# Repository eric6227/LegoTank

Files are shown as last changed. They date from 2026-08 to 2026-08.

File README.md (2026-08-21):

# LEGO Tank Remote Control Project — 宏梦·初号机

一个以 ESP32 / ESP32-CAM 为硬件边缘节点、以 Python 为上位机控制层的遥控坦克与实时观测工程。项目包含完整的硬件电路设计、3D 打印结构件、LEGO 车身拼搭方案、控制固件和上位机控制软件。

效果图

> 宏梦·初号机是一台基于乐高 Technic 框架的履带遥控车，通过 WiFi + MQTT 实现远程操控与实时图传。

> [碰撞测试视频](https://www.bilibili.com/video/BV1AC866cEPq)

---

## 目录

- [1. 项目概览](#1-项目概览)
- [2. 系统架构](#2-系统架构)
- [3. 目录结构](#3-目录结构)
- [4. 硬件组成](#4-硬件组成)
- [5. MQTT 通信协议](#5-mqtt-通信协议)
- [6. 配置说明](#6-配置说明)
- [7. 伺服电机控制](#7-伺服电机控制)
- [8. 运行步骤](#8-运行步骤)
- [9. 安全说明](#9-安全说明)
- [10. 已知运行注意事项](#10-已知运行注意事项)
- [11. 许可证](#11-许可证)
- [12. 代码来源声明](#12-代码来源声明)

---

## 1. 项目概览

该仓库提供以下能力：

- 由控制软件在本地展示摄像头视频与 HUD 叠加信息。
- 通过 MQTT 接收控制板遥测包与监控板遥测包。
- 将控制板和摄像头监控板的信号强度、状态字段、统一进入 overlay 页面。
- 支持手动按键控制、蓝牙/键盘远程控制输入与视频流浏览器观测。
- 通过本地 HTTP 服务向浏览器或 OBS 端源提供稳定的 overlay 页面与 telemetry 接口。
- 提供完整的乐高拼搭说明书以及工程文件，便于复刻
- 提供完整的 3D 打印件设计（换挡器、摄像头固定座等）。
- 提供可直接在嘉立创下单的 PCB 电路板设计文件（含 Gerber、BOM、钢网）。

---

## 2. 系统架构

该工程可理解为三层：

1. **边缘硬件层**：ESP32 控制板 + ESP32-CAM 监控板固件。
2. **协议与数据层**：MQTT 主题、JSON payload 与 telemetry 语义。
3. **控制与展示层**：PyQt6 QWebEngine HUD / HTTP 页面 / Python 控制循环。

```
┌─────────────────────────────────────────────────┐
│                  上位机 (PC)                      │
│  ┌───────────────────────────────────────────┐  │
│  │  infinite_rc_controller.py                │  │
│  │  - PyQt6 HUD (QWebEngineView)             │  │
│  │  - HTTP Overlay Server (:8080)            │  │
│  │  - MQTT Client (控制指令 + 遥测)           │  │
│  │  - 键盘/手柄输入处理                       │  │
│  └───────────────────────────────────────────┘  │
└──────────────┬──────────────┬───────────────────┘
               │ MQTT         │ HTTP (视频流)
               ▼              ▼
┌──────────────────────┐  ┌──────────────────────┐
│  ESP32 控制板         │  │  ESP32-CAM 监控板     │
│  - 电机驱动 (TB6612)  │  │  - OV2640 摄像头      │
│  - 舵机控制 (M1/M2/M3)│  │  - WiFi 视频流        │
│  - 电池电压检测       │  │  - MQTT 遥测上报      │
│  - MQTT 指令接收      │  │  - 摄像头参数远程配置  │
│  - 超时安全停车       │  │                       │
└──────────────────────┘  └──────────────────────┘
```

---

## 3. 目录结构

```
legotank/
├── README.md                                 # 本文件
├── LICENSE                                   # 代码 MIT 许可证
├── MQTT_MESSAGE_FORMAT.md                    # MQTT 协议参考文档
├── requirements.txt                          # Python 运行依赖
├── config.yaml                               # 控制软件运行配置
├── .gitignore                                # Git 忽略规则
│
├── control_software/                         # 上位机控制软件
│   ├── infinite_rc_controller.py             # 主控制程序入口
│   └── config.yaml                           # 默认配置预设
│
├── legotank_esp32/                           # ESP32 控制板固件
│   ├── legotank_esp32.ino                    # 主固件源码
│   └── config.h                              # 引脚/参数配置
│
├── legotank_monitor/                         # ESP32-CAM 监控板固件
│   ├── legotank_monitor.ino                  # 主固件源码
│   ├── app_httpd.cpp                         # HTTP 视频流服务
│   ├── camera_index.h                        # 摄像头 Web 页面
│   ├── camera_pins.h                         # 摄像头引脚定义
│   ├── board_config.h                        # 板级配置
│   └── ci.yml                                # CI 构建配置
│
├── test_tools/                               # 测试与调试工具
│   ├── debug.py                              # 一键启动调试环境
│   ├── telemetry_monitor.py                  # MQTT 遥测 TUI 监控器
│   └── test_mqtt_server.py                   # MQTT 连通性测试脚本
│
├── 3D_models/                                # 3D 打印件设计
│   ├── LICENSE                               # CC0 1.0 许可证
│   ├── legotank配套打印件.FCStd              # FreeCAD 源文件
│   ├── legotank配套打印件-换挡器（2个）.stl  # 换挡器打印件
│   ├── legotank配套打印件-控制板换挡舵机固定座-1.6mmPCB.stl
│   └── legotank配套打印件-摄像头固定座.stl  # 摄像头固定座
│
├── PCBs/                                     # PCB 电路板设计
│   ├── LICENSE                               # CC0 1.0 许可证
│   ├── 说明.md                               # PCB 使用说明
│   ├── legotank.zip                          # Gerber 文件
│   ├── legotank.xlsx                         # 器件位置文件 (SMT)
│   ├── legotank-BOM.xlsx                     # BOM 器件列表
│   ├── 钢网.zip                              # 钢网文件
│   └── 乐高履带物联网遥控车.zip              # 嘉立创 EDA 工程文件
│
└── lego/                                     # LEGO 拼搭设计
    ├── LICENSE                               # CC0 1.0 许可证
    ├── legotank.io                           # Studio 设计文件
    ├── legotank.csv                          # 零件清单
    ├── legotank.xml                          # 零件 XML
    ├── legotank.pdf                          # 拼搭说明书
    └── render/
        └── legotank.png                      # 渲染效果图
```

---

## 4. 硬件组成

### 4.1 控制板 (ESP32)

| 组件 | 说明 |
|---|---|
| 主控 | ESP32 双核 240MHz |
| 电机驱动 | TB6612FNG 双路 H 桥 |
| 舵机 | M1 换挡舵机 (0-180°)、M2 大灯 (PWM)、M3 逗猫棒 (PWM) |
| 电源 | 3S LiPo (11.1V) 电池，含分压电压检测 |
| 通信 | WiFi 2.4GHz + MQTT |

### 4.2 监控板 (ESP32-CAM)

| 组件 | 说明 |
|---|---|
| 主控 | ESP32-CAM (AI-Thinker) |
| 摄像头 | OV2640 200万像素，最高 1600×1200 |
| 视频流 | MJPEG over HTTP |
| 通信 | WiFi 2.4GHz + MQTT |

### 4.3 结构件

- **防滚架**：F1 赛车级安全理念，翻滚时保护内部组件不接触地面。
- **换挡器**：两档机械变速，通过 M1 舵机切换高低档位。
> PS：其实低速档已经够快了，换挡结构比较复杂，可以使用手动挡+用绳子把挡位固定在低速（后面）
- **摄像头固定座**：安装在车体前部，提供第一视角。
- 所有结构件均为 3D 打印件，FreeCAD 源文件可供修改。

### 4.4 PCB 电路板

PCB 使用嘉立创 EDA 设计，仓库提供：
- Gerber 文件（可直接下单生产）
- BOM 器件列表（可在立创商城直接购买）
- 钢网文件（可以选择开钢网，这样焊接会方便很多，毕竟全是 0603 的贴片元件）
- 器件位置文件（用于 SMT 贴片）

---

## 5. MQTT 通信协议

本仓库中的 MQTT 通信与 JSON 字段的完整规范请见 [MQTT_MESSAGE_FORMAT.md](MQTT_MESSAGE_FORMAT.md)。

### 5.1 主题结构

| 主题 | 方向 | 说明 |
|---|---|---|
| `tank/cmd` | PC → ESP32 | 控制指令 |
| `tank/telemetry/control` | ESP32 → PC | 控制板遥测数据 |
| `tank/telemetry/monitor` | ESP32-CAM → PC | 监控板遥测数据 |
| `tank/cmd/camera` | PC → ESP32-CAM | 摄像头参数配置 |

### 5.2 控制指令字段

| 字段 | 类型 | 取值范围 | 说明 |
|---|---|---|---|
| `L` | 整数 | -255~255 | 左电机 PWM 占空比 |
| `R` | 整数 | -255~255 | 右电机 PWM 占空比 |
| `M1` | 整数 | 0~180 | 换挡舵机角度 |
| `M2` | 整数 | 0~255 | 大灯电平值 |
| `M3` | 整数 | 0~255 | 逗猫棒电平值 |

### 5.3 安全机制

- **指令超时保护 (Watchdog)**：若 500ms 内未收到任何 `tank/cmd` 消息，ESP32 自动停车。
- **电机换向保护**：（硬编码在控制板中，上位机发送指令时也会遵守）检测到方向切换时先强制输出 0 一段时间，保护驱动电路。

---

## 6. 配置说明

### 6.1 控制软件配置

控制软件使用 [control_software/config.yaml](control_software/config.yaml) 作为默认预设配置文件。配置文件不存在时会自动生成默认配置文件。

该文件包含：

- **MQTT 连接**：broker 地址、端口、订阅主题。
- **视频流**：stream_url、分辨率、画质、帧率。
- **控制参数**：按键绑定、功率上限、加速率、制动强度、转向因子。
- **换挡参数**：高低档位阈值、换挡时间、M1 舵机角度。
- **伺服电机**：数量、名称、段数、idle 电平、各段按键/电平/过渡时间/触发方式。
- **视频处理**：翻转、旋转、自动画质调节。

控制软件在启动时会优先从同目录下的 YAML 文件读取参数，并在代码里用 `DEFAULT_CONFIG` 作为代码级默认兜底。

### 6.2 控制板固件配置

控制板配置见 [legotank_esp32/config.h](legotank_esp32/config.h)，包含：

- 引脚定义（电机、舵机、电池检测）
- PWM 参数（频率、分辨率）
- 电池分压电阻值
- WiFi / MQTT 连接参数
- 运行时参数（遥测间隔、看门狗超时、换向保护时间）

---

## 7. 伺服电机控制

控制软件通过"伺服电机"设置页提供灵活的伺服电机分段控制：

- **数量**：可配置 1~8 个伺服电机（默认 2 个），M1 留给换挡舵机专用。
- **段数**：每个伺服电机可独立配置 1~8 段，动态增减段数后界面自动重建。
- **电平值**：使用 0~255 电平值而非角度，M2/M3 引脚直接输出 PWM（频率 1200Hz，分辨率 8bit），消除 LED 频闪。
- **不触发电平**：每个伺服电机有独立的 idle 电平值。
- **触发方式**：每段支持"按住触发"（按下生效，释放回 idle）和"按键切换"（按一次切换，再按一次回 idle）两种模式。
- **平滑过渡**：每段可配置独立的过渡时间，伺服电机会在设定时间内平滑过渡到目标电平。

按键行为逻辑：
- **按键切换**：当前为该段 → 回到不触发；当前不是该段 → 切换到该段。
- **按住触发**：按住 → 切到该段；释放 → 回到不触发。
- 在任意一段按下另一段的按键，就切换到那一段。

---

## 8. 运行步骤

### 8.1 环境准备

1. 安装 Python 依赖：

   ```bash
   pip install -r requirements.txt
   ```

2. 确保 MQTT Broker（如 Mosquitto）在局域网内正常运行。

3. 将 ESP32 控制板和 ESP32-CAM 监控板固件分别烧录到对应硬件。

### 8.2 启动控制软件

```bash
python control_software/infinite_rc_controller.py
```

### 8.3 测试工具

- **遥测监控**：`python test_tools/telemetry_monitor.py` — TUI 界面实时查看控制板和监控板遥测数据。
- **连通性测试**：`python test_tools/test_mqtt_server.py` — 验证 MQTT Broker 是否正常工作。
- **一键调试**：`python test_tools/debug.py` — 同时启动控制软件和遥测监控。

### 8.4 快速 MQTT 测试

```bash
# 发送控制指令
mosquitto_pub -h 192.168.2.45 -t tank/cmd -m '{"L":200,"R":200}'

# 订阅遥测
mosquitto_sub -h 192.168.2.45 -t tank/telemetry/control
```

---

## 9. 安全说明

该项目当前的通信设计是：

- MQTT Broker 连接：默认基于 TCP / 1883 端口。
- MQTT 载荷：JSON 文本，未做协议层加密。
- 视频流：HTTP / 视频源地址，由本地网络环境提供。

因此，当前工程存在明显的安全限制：

- 消息在网络中没有 TLS / SSL / MQTT over TLS 的保护。
- 车体命令、遥测、RSSI、系统状态等都可能以明文形式经过网络。
- 设备接入环境应当控制在受信任的局域网，或后续增加 VPN / SSH 隧道 / MQTT TLS / 设备级认证后再投入真实生产场景。

---

## 10. 已知运行注意事项

- 该项目是物理硬件驱动型工程，强依赖网络与 MQTT Broker 可达性。
- 如果设备没有实时发布消息，控制软件会在界面中持续显示等待状态。
- `telemetry_monitor.py` 是排查 MQTT 输出字段与主题路由的辅助工具。
- 如果某个字段没有被摄像头监控板或控制板正常填充，窗口 HUD 也会出现"图层灰"/"缺字段"的显示现象。
- ESP32-CAM 监控板需设置静态 IP，确保视频流地址稳定。

---

## 11. 许可证

本项目采用**双许可证**模式，按文件类型分别适用不同协议：

| 内容类型 | 许可协议 | 适用范围 |
|---|---|---|
| **代码** | [MIT License](./LICENSE) | `.py`、`.ino`、`.cpp`、`.h`、`.yml`、`.yaml` 等源代码文件 |
| **3D 模型** | [CC0 1.0](./3D_models/LICENSE) | `.stl`、`.FCStd` 等 3D 打印设计文件 |
| **PCB 设计** | [CC0 1.0](./PCBs/LICENSE) | Gerber、BOM、钢网、位置文件等电路板设计文件 |
| **LEGO 设计** | [CC0 1.0](./lego/LICENSE) | `.io`、`.xml`、`.csv`、`.pdf` 等乐高拼搭设计文件 |
| **文档** | [CC0 1.0](./README.md) | `README.md`、`MQTT_MESSAGE_FORMAT.md`、`视频文案.md` 等文档 |

简单来说：
- **代码**：MIT 协议，可自由使用、修改、分发，需保留版权声明。
- **非代码资产**（3D 模型、PCB、LEGO 设计、文档）：CC0 1.0 协议，完全贡献至公共领域，可自由使用、修改、分发（含商业用途），无需署名。

各目录下的 `LICENSE` 文件为该目录内容的许可协议，具有法律效力。

---

## 12. 代码来源声明

本仓库中的可执行代码、协议处理与工程骨架由 AI 辅助工具生成或改写。代码不仅可用于功能验证，也可以作为后续硬件控制系统的演进基础。使用者应当自行验证所有字段、协议、设备连接与安全策略是否适用于实际应用场景。使用者不规范使用或者失误造成的后果与开发者本人无关。

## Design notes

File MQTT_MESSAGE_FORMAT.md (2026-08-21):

# 玩具坦克 ESP32 MQTT 通信协议

> 适用固件：`legotank_esp32/legotank_esp32.ino`

## 1. 控制指令（上位机 → ESP32）

**Topic：** `tank/cmd`

**格式：** JSON，UTF-8 文本

### 字段说明

| 字段 | 类型 | 取值范围 | 说明 |
| ---- | --- | --- | --- |
| `L`  | 整数 | `-255 ~ 255`  | 左电机 PWM 占空比，负值倒车，正值前进  |
| `R`  | 整数 | `-255 ~ 255`  | 右电机 PWM 占空比，负值倒车，正值前进  |
| `M1` | 整数 | `0 ~ 180` | 换挡舵机角度（0° ~ 180°） |
| `M2` | 整数 | `0 ~ 255` | 大灯电平值（直接 PWM 占空比，0=关闭，255=最亮）  |
| `M3` | 整数 | `0 ~ 255` | 逗猫棒电平值（直接 PWM 占空比，0=关闭，255=最大）  |

- 所有字段均为**可选**；缺失的字段保持上一次值不变。
- 动力差转向、差速调速等逻辑必须在上位机完成，ESP32 直接使用原始值驱动硬件。
- M2/M3 使用直接 PWM 控制（频率 1200Hz，分辨率 8bit），可有效消除 LED 频闪。

### 示例

```json
{
  "L": 200,
  "R": -150,
  "M1": 90,
  "M2": 128,
  "M3": 0
}
```

含义：

- 左电机以 `200/255` 功率前进
- 右电机以 `150/255` 功率倒车
- M1 舵机回到中位
- M2 大灯电平 128（半亮）
- M3 逗猫棒电平 0（关闭）

### 仅控制舵机示例

```json
{
  "M1": 120,
  "M3": 255
}
```

电机保持当前状态不变。

---

## 2. 遥测数据（ESP32 → 上位机）

**Topic：** `tank/telemetry`

**格式：** JSON，发送间隔约 `500ms`（可在 `config.h` 中修改 `TELEMETRY_MS`）

### 字段说明

| 字段 | 类型 | 单位 | 说明 |
| --- | --- | --- | --- |
| `vbat`  | 浮点数 | V | 3S LiPo 电池电压 |
| `L` | 整数 | `-255~255` | 当前左电机实际输出 |
| `R` | 整数 | `-255~255` | 当前右电机实际输出 |
| `M1` | 整数 | `0~180`  | 当前 M1 舵机角度 |
| `M2` | 整数 | `0~255`  | 当前 M2 电平（大灯） |
| `M3` | 整数 | `0~255`  | 当前 M3 电平（逗猫棒） |
| `rssi`  | 整数 | dBm | WiFi 信号强度 |
| `uptime`| 整数 | ms | ESP32 运行时间 |

### 示例

```json
{
  "vbat": 11.34,
  "L": 200,
  "R": -150,
  "M1": 90,
  "M2": 128,
  "M3": 0,
  "rssi": -45,
  "uptime": 123456
}
```

---

## 3. 安全机制

- **指令超时保护（Watchdog）：** 若 `1000ms` 内未收到任何 `tank/cmd` 消息，ESP32 会自动将左右电机置 0（停车），舵机保持原位。
- 该机制可防止上位机崩溃、网络中断或程序异常时坦克失控。

---

## 4. 快速测试

使用 `mosquitto_pub` 或任意 MQTT 客户端向 `tank/cmd` 发送：

```bash
mosquitto_pub -h 192.168.2.45 -t tank/cmd -m '{"L":200,"R":200}'
```

订阅遥测：

```bash
mosquitto_sub -h 192.168.2.45 -t tank/telemetry
```

> 请将 `192.168.2.45` 替换为实际 MQTT 服务器地址（在 `config.h` 中配置）。

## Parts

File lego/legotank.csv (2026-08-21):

BLItemNo | ElementId | LdrawId | PartName | BLColorId | LDrawColorId | ColorName | ColorCategory | Qty | Weight
14720 | 6396959 | 14720.dat | Technic, Liftarm, Modified H-Shape Thick 3 x 5 Perpendicular | 85 | 72 | Dark Bluish Gray | Solid Colors | 2
15100 | 6282142 | 15100.dat | Technic, Pin with Friction Ridges and Pin Hole | 86 | 71 | Light Bluish Gray | Solid Colors | 2 | 0.4
15100 | 6282140 | 15100.dat | Technic, Pin with Friction Ridges and Pin Hole | 11 | 0 | Black | Solid Colors | 4 | 0.4
15458 | 6127205 | 15458.dat | Technic, Panel Plate 3 x 11 x 1 | 85 | 72 | Dark Bluish Gray | Solid Colors | 3 | 7
18654 | 6183784 | 18654.dat | Technic, Liftarm Thick 1 x 1 (Spacer) | 86 | 71 | Light Bluish Gray | Solid Colors | 4 | 0.17
18946 | 6100930 | 18946.dat | Technic, Gear 16 Tooth with Clutch on Both Sides | 5 | 4 | Red | Solid Colors | 4 | 0.84
18947 | 6100931 | 18947.dat | Technic Driving Ring 3L | 85 | 72 | Dark Bluish Gray | Solid Colors | 2 | 1.97
22961 | 6123815 | 22961.dat | Technic, Axle and Pin Connector Hub with 1L Axle | 86 | 71 | Light Bluish Gray | Solid Colors | 2 | 0.34
26287 | 6273211 | 26287.dat | Technic, Axle Connector 3L | 5 | 4 | Red | Solid Colors | 2 | 0.7
2780 | 6279875 | 2780.dat | Technic, Pin with Short Friction Ridges | 11 | 0 | Black | Solid Colors | 83 | 0.16
32054 | 6347789 | 32054.dat | Technic, Pin 3L with Friction Ridges and Stop Bush | 5 | 4 | Red | Solid Colors | 8 | 0.33
32062 | 4142865 | 32062.dat | Technic, Axle 2L Notched | 5 | 4 | Red | Solid Colors | 2 | 0.26
32073 | 4211639 | 32073.dat | Technic, Axle 5L | 86 | 71 | Light Bluish Gray | Solid Colors | 4 | 0.66
4265c | 6271167 | 32123a.dat | Technic Bush 1/2 Smooth | 3 | 14 | Yellow | Solid Colors | 2 | 0.1
32198 | 6031956 | 32198.dat | Technic, Gear 20 Tooth Bevel | 86 | 71 | Light Bluish Gray | Solid Colors | 2 | 0.75
32269 | 6346535 | 32269.dat | Technic, Gear 20 Tooth Double Bevel | 11 | 0 | Black | Solid Colors | 4 | 1.4
32278 | 4542576 | 32278.dat | Technic, Liftarm Thick 1 x 15 | 85 | 72 | Dark Bluish Gray | Solid Colors | 4 | 4
32278 | 4542577 | 32278.dat | Technic, Liftarm Thick 1 x 15 | 86 | 71 | Light Bluish Gray | Solid Colors | 1 | 4
32291 | 6280394 | 32291.dat | Technic, Axle and Pin Connector Perpendicular Double | 11 | 0 | Black | Solid Colors | 1 | 0.6
32316 | 4142132 | 32316.dat | Technic, Liftarm Thick 1 x 5 | 5 | 4 | Red | Solid Colors | 2 | 1.21
32316 | 4211651 | 32316.dat | Technic, Liftarm Thick 1 x 5 | 86 | 71 | Light Bluish Gray | Solid Colors | 3 | 1.21
32524 | 4495931 | 32524.dat | Technic, Liftarm Thick 1 x 7 | 85 | 72 | Dark Bluish Gray | Solid Colors | 9 | 1.74
32524 | 4495933 | 32524.dat | Technic, Liftarm Thick 1 x 7 | 5 | 4 | Red | Solid Colors | 2 | 1.74
32524 | 4495930 | 32524.dat | Technic, Liftarm Thick 1 x 7 | 86 | 71 | Light Bluish Gray | Solid Colors | 2 | 1.74
32526 | 4211713 | 32526.dat | Technic, Liftarm, Modified Bent Thick L-Shape 3 x 5 | 86 | 71 | Light Bluish Gray | Solid Colors | 4 | 1.77
3705 | 370526 | 3705.dat | Technic, Axle 4L | 11 | 0 | Black | Solid Colors | 6 | 0.6
3707 | 370726 | 3707.dat | Technic, Axle 8L | 11 | 0 | Black | Solid Colors | 2 | 1.18
3713 | 6275844 | 3713.dat | Technic Bush | 86 | 71 | Light Bluish Gray | Solid Colors | 14 | 0.14
3737 | 373726 | 3737.dat | Technic, Axle 10L | 11 | 0 | Black | Solid Colors | 2 | 1.49
40490 | 6102449 | 40490.dat | Technic, Liftarm Thick 1 x 9 | 86 | 71 | Light Bluish Gray | Solid Colors | 1 | 2.59
44294 | 4211805 | 44294.dat | Technic, Axle 7L | 86 | 71 | Light Bluish Gray | Solid Colors | 1 | 1.05
4519 | 4211815 | 4519.dat | Technic, Axle 3L | 86 | 71 | Light Bluish Gray | Solid Colors | 2 | 0.43
57518 | 6366190 | 57518.dat | Technic, Link Tread Wide with 2 Pin Holes | 85 | 72 | Dark Bluish Gray | Solid Colors | 92 | 1.35
57519 | 4582792 | 57519.dat | Technic Tread Sprocket Wheel Large | 11 | 0 | Black | Solid Colors | 6 | 5.1
58120c01 | 6151440 | 58120.dat | Electric, Motor 9V Power Functions M with Dark Bluish Gray Bottom | 86 | 71 | Light Bluish Gray | Solid Colors | 2 | 33.5
60484 | 4552348 | 60484.dat | Technic, Liftarm, Modified T-Shape Thick 3 x 3 | 86 | 71 | Light Bluish Gray | Solid Colors | 6 | 1.19
64179 | 4539880 | 64179.dat | Technic, Liftarm, Modified Frame Thick 5 x 7 Open Center | 86 | 71 | Light Bluish Gray | Solid Colors | 6 | 5.3
6558 | 6299413 | 6558.dat | Technic, Pin 3L with Friction Ridges | 7 | 1 | Blue | Solid Colors | 16 | 0.31
6589 | 6589194 | 6589.dat | Technic, Gear 12 Tooth Bevel | 86 | 71 | Light Bluish Gray | Solid Colors | 2 | 0.29
6641 | 6313493 | 6641.dat | Technic Changeover Catch | 5 | 4 | Red | Solid Colors | 2 | 0.5
73507 | 6362250 | 73507.dat | Technic, Liftarm, Modified Perpendicular Holes Thick 1 x 11 | 86 | 71 | Light Bluish Gray | Solid Colors | 2
94925 | 4640536 | 94925.dat | Technic, Gear 16 Tooth - Axle Hole with Closed Sides | 86 | 71 | Light Bluish Gray | Solid Colors | 4 | 0.7
Total qty | Total Weight
324 | 401.67 +a

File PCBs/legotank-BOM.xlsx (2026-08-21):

No. | Quantity | Comment | Designator | Footprint | Value | Manufacturer Part | Manufacturer | Supplier Part | Supplier
1 | 2 | TS-1088-AR02016 | BOOT,BootOption | SW-SMD_L3.9-W3.0-P4.45 |  | TS-1088-AR02016 | XUNPU(讯普) | C720477 | LCSC
2 | 1 | 22uF | C1 | C0603 | 22uF | CL10A226MQ8NRNC | SAMSUNG(三星) | C59461 | LCSC
3 | 5 | 100nF | C2,C3,C6,C9,C11 | C0603 | 100nF | CL10B104KB8NNNC | SAMSUNG(三星) | C1591 | LCSC
4 | 2 | 12pF | C3(NC),C4(NC) | C0603 | 12pF | CL10C120JB8NNNC | SAMSUNG(三星) | C38523 | LCSC
5 | 1 | 1uF | C5 | C0603 | 1uF | CGA0603X5R105K160JT | HRE(芯声) | C6119849 | LCSC
6 | 1 | 1000uF | C7 | CAP-SMD_BD10.0-L10.3-W10.3-FD | 1000uF | JVJ16V1000M10x10 | JIERR(捷而瑞) | C46550395 | LCSC
7 | 2 | 10uF | C8,C10 | C0603 | 10uF | CGA0603X5R106K100JT | HRE(芯声) | C6119842 | LCSC
8 | 1 | XT30UPB-M | CN1 | CONN-TH_XT30UPB-M |  | XT30UPB-M | AMASS(艾迈斯) | C428721 | LCSC
9 | 2 | PZ254V-11-04P | JTAG,UART | HDR-TH_4P-P2.54-V-M |  | PZ254V-11-04P | XFCN(兴飞) | C2691448 | LCSC
10 | 3 | PZ254V-11-03P | M1,M2,M3 | HDR-TH_3P-P2.54-V-M_PZ254V-11-03P |  | PZ254V-11-03P | XFCN(兴飞) | C2937625 | LCSC
11 | 2 | WAFER-XH254Z-4AM | ML,MR | CONN-TH_WAFER-XH2.54-4PZZ-H62 |  | WAFER-XH254Z-4AM | HANBO(汉博) | C22751824 | LCSC
12 | 1 | 100kΩ | R1 | R0603 | 100kΩ | FRC0603J104 TS | FOJAN(富捷) | C2907088 | LCSC
13 | 1 | 5MΩ | R1(NC) | R0603 | 5MΩ | HVC0603T5004FET | Ohmite | C2479256 | LCSC
14 | 1 | 30kΩ | R2 | R0603 | 30kΩ | FRC0603F3002TS | FOJAN(富捷) | C2907025 | LCSC
15 | 3 | 0Ω | R2(NC),R3(NC),R6 | R0603 | 0Ω | FRC0603F0000TS | FOJAN(富捷) | C2906974 | LCSC
16 | 1 | 4.7kΩ | R4 | R0603 | 4.7kΩ | FRC0603J472 TS | FOJAN(富捷) | C2907166 | LCSC
17 | 1 | 10kΩ | R5 | R0603 | 10kΩ | FRC0603J103 TS | FOJAN(富捷) | C2930027 | LCSC
18 | 1 | 2.4GHz | U1 | WIFI-SMD_ESP32-WROOM-32E | 2.4GHz | ESP32-WROOM-32E-N4 | ESPRESSIF(乐鑫) | C701341 | LCSC
19 | 1 | 1N4007 | U2 | SMA_L4.3-W2.6-LS5.1-RD |  | 1N4007 |  | C9900004759 | LCSC
20 | 1 | TB6612FNG,C,8,EL | U3 | SSOP-24_L8.3-W5.6-P0.65-LS7.6-BL |  | TB6612FNG,C,8,EL | TOSHIBA(东芝) | C141517 | LCSC
21 | 1 | AMS1117-3.3S | U4 | SOT-89-3_L4.5-W2.4-P1.50-LS4.0-BR |  | AMS1117-3.3S | TECH PUBLIC(台舟) | C46473005 | LCSC
22 | 1 | AMS1117-5.0S | U5 | SOT-89-3_L4.5-W2.5-P1.50-LS4.2-BR |  | AMS1117-5.0S | TECH PUBLIC(台舟) | C46473006 | LCSC
23 | 1 | 8K32.768XP | X1(NC) | CRYSTAL-SMD_L7.0-W3.2-LS7.5 |  | 8K32.768XP | HUAXIN(华昕) | C19723459 | LCSC

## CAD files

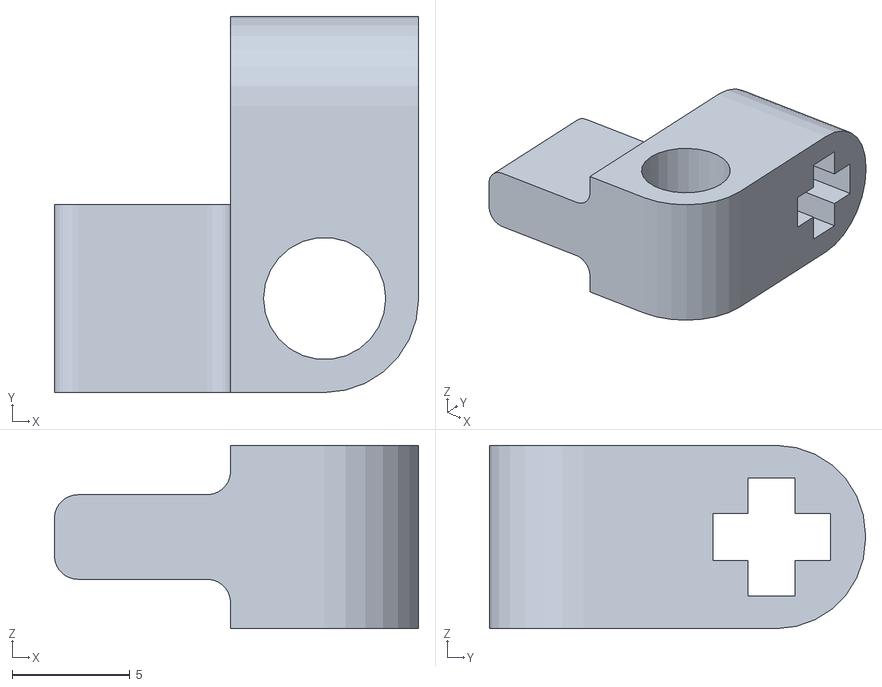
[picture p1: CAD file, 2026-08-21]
3D_models/legotank配套打印件-换挡器（2个）.stl
15.5 x 16.0 x 7.80

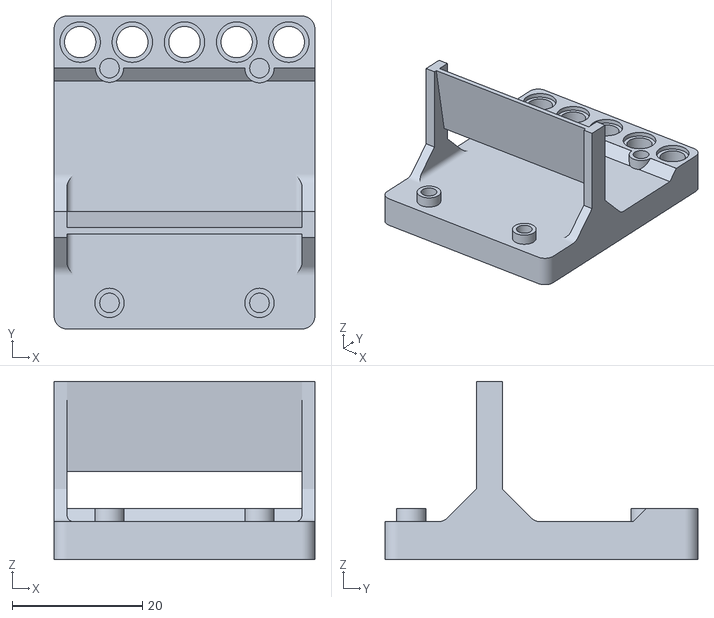
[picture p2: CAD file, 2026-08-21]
3D_models/legotank配套打印件-摄像头固定座.stl
40.0 x 48.0 x 27.3

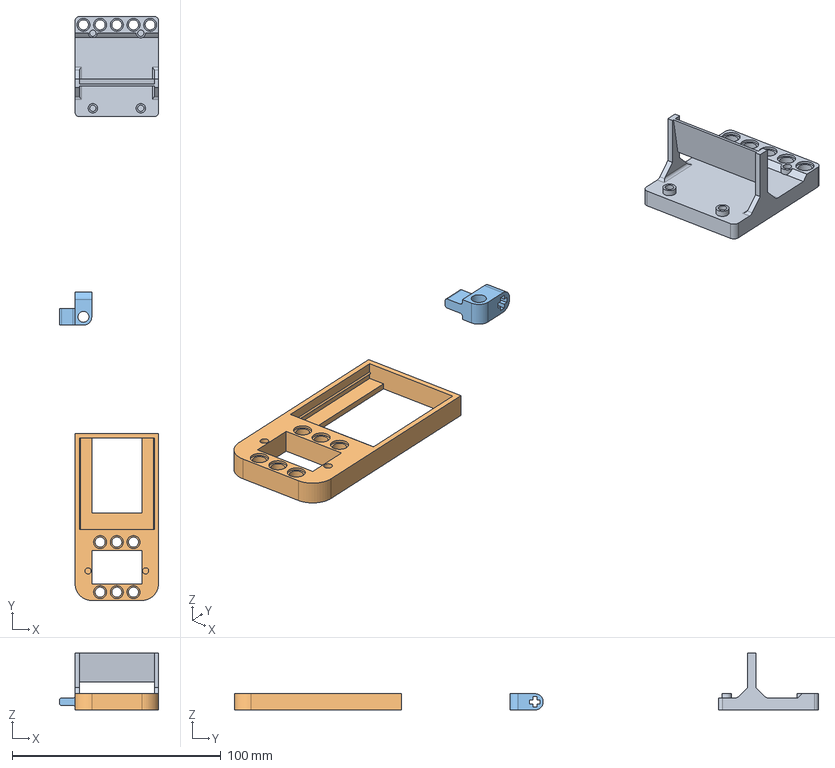
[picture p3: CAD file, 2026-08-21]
3D_models/legotank配套打印件.FCStd
47.5 x 280.0 x 27.3 mm
摄像头固定座
控制板换挡舵机固定座-1.6mmPCB
换挡器（2个）

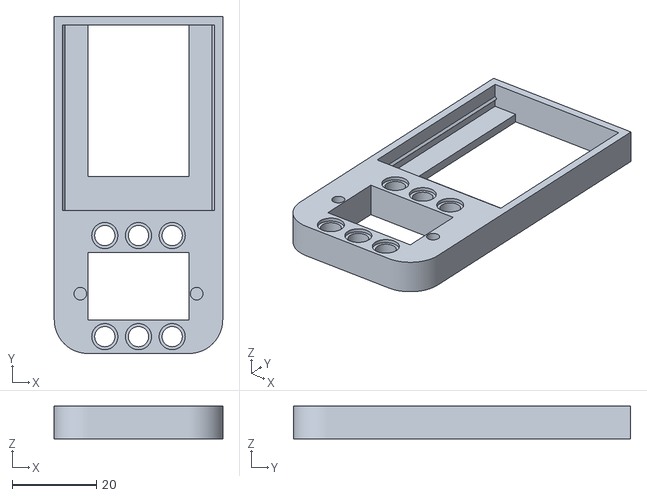
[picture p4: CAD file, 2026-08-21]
3D_models/legotank配套打印件-控制板换挡舵机固定座-1.6mmPCB.stl
40.0 x 80.0 x 7.80

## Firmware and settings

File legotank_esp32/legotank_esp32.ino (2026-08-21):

/*
 * Copyright (c) 2026 eric6227
 * Released under the MIT License. See LICENSE file in the project root for full text.
 *
 * 玩具坦克 ESP32 控制板主程序
 *
 * 功能：
 *   1. 通过 MQTT 接收上位机发来的原始控制量
 *   2. 直接驱动左/右电机和三个舵机 M1/M2/M3
 *   3. 定时回传电池电压、当前输出、WiFi 信号等遥测数据
 *   4. 指令超时自动停车（failsafe）
 *
 * 依赖库（请通过 Arduino IDE 库管理器安装）：
 *   - PubSubClient（by Nick O'Leary）
 *   - ArduinoJson（by Benoit Blanchon）
 *
 * 硬件：ESP32 + TB6612FNG 双路电机驱动 + 3 路舵机 + 电池分压检测
 */

#include <WiFi.h>
#include <PubSubClient.h>
#include <ArduinoJson.h>
#include "config.h"

// ============================================================
// 兼容 ESP32 Arduino Core 2.x 与 3.x 的 LEDC API 差异
// ============================================================
#if defined(ESP_ARDUINO_VERSION_MAJOR) && (ESP_ARDUINO_VERSION_MAJOR >= 3)
  #define LEDC_NEW_API 1
#else
  #define LEDC_NEW_API 0
#endif

// 电机 / 舵机 PWM 引脚
const uint8_t MOTOR_PINS[2] = { LEFT_PWM, RIGHT_PWM };
const uint8_t SERVO_PINS[3] = { SERVO1_PIN, SERVO2_PIN, SERVO3_PIN };

#if !LEDC_NEW_API
// Core 2.x 需要手动分配通道号
const uint8_t MOTOR_CH[2] = { 0, 1 };
const uint8_t SERVO_CH[3] = { 2, 3, 4 };
const uint8_t SERVO23_CH[2] = { 5, 6 };  // M2/M3 直接PWM通道
#endif

// ============================================================
// 全局对象与状态
// ============================================================
WiFiClient   wifiClient;
PubSubClient mqttClient(wifiClient);

// 当前控制量
int16_t motorL = 0;   // 左电机：-255 ~ 255
int16_t motorR = 0;   // 右电机：-255 ~ 255
int16_t servoM1 = 90; // M1 舵机角度：0 ~ 180
uint8_t servoM2 = 0;   // M2 电平：0 ~ 255（直接 PWM）
uint8_t servoM3 = 0;   // M3 电平：0 ~ 255（直接 PWM）

uint32_t lastCmdMs    = 0;  // 上次收到指令的时间
uint32_t telemetryMs  = 0;  // 上次遥测发送时间
bool     wifiWasConnected = false; // 用于检测 WiFi 断线重连

// RSSI 持续过低重连配置（可通过 MQTT tank/cmd 下发修改）
int rssiReconnectThreshold = -75;         // 默认 -75dBm
unsigned long rssiReconnectDelayMs = 10000; // 默认持续 10 秒才触发重连
unsigned long rssiBelowThresholdSince = 0;  // RSSI 首次低于阈值的时间戳

// 电机换向保护状态
int16_t  appliedMotorL = 0;          // 最近一次实际输出到驱动的左电机值
int16_t  appliedMotorR = 0;          // 最近一次实际输出到驱动的右电机值
uint32_t directionChangeHoldEnd = 0; // 换向保持结束时间
bool     directionChangeHolding = false;

// ============================================================
// LEDC 辅助函数
// ============================================================
bool pwmAttach(uint8_t pin, uint32_t freq, uint8_t resolution, uint8_t channel) {
#if LEDC_NEW_API
  (void)channel;
  bool ok = ledcAttach(pin, freq, resolution);
  if (!ok) {
    Serial.print("[PWM] 引脚 ");
    Serial.print(pin);
    Serial.println(" 初始化失败");
  }
  return ok;
#else
  ledcSetup(channel, freq, resolution);
  ledcAttachPin(pin, channel);
  return true;
#endif
}

void pwmWrite(uint8_t pin, uint8_t channel, uint32_t duty) {
#if LEDC_NEW_API
  (void)channel;
  ledcWrite(pin, duty);
#else
  ledcWrite(channel, duty);
#endif
}

// ============================================================
// 电机控制
// ============================================================
void setMotor(uint8_t side, int speed) {
  if (side > 1) return;

  speed = constrain(speed, -255, 255);

  uint8_t in1, in2;
  if (side == 0) {
    in1 = LEFT_AIN1;
    in2 = LEFT_AIN2;
  } else {
    in1 = RIGHT_BIN1;
    in2 = RIGHT_BIN2;
  }

  if (speed > 0) {
    digitalWrite(in1, HIGH);
    digitalWrite(in2, LOW);
  } else if (speed < 0) {
    digitalWrite(in1, LOW);
    digitalWrite(in2, HIGH);
  } else {
    // 刹车/停止：两片输入都拉低
    digitalWrite(in1, LOW);
    digitalWrite(in2, LOW);
  }

  uint32_t duty = abs(speed);  // 8 位分辨率，0-255
#if !LEDC_NEW_API
  uint8_t ch = MOTOR_CH[side];
#else
  uint8_t ch = 0;
#endif
  pwmWrite(MOTOR_PINS[side], ch, duty);
}

// ============================================================
// 舵机控制（角度 -> 脉宽 -> 16 位占空比）
// ============================================================
void setServo(uint8_t idx, int angle) {
  if (idx > 2) return;

  angle = constrain(angle, 0, 180);

  // 把角度映射为脉宽（微秒）
  int pulseUs = map(angle, 0, 180, SERVO_MIN_US, SERVO_MAX_US);

  // 50Hz 周期 = 20000us，16 位最大值为 65535
  uint32_t maxDuty = (1UL << SERVO_RES) - 1;
  uint32_t duty = (uint32_t)((pulseUs / 20000.0) * maxDuty);
  duty = constrain(duty, 0, maxDuty);

#if !LEDC_NEW_API
  uint8_t ch = SERVO_CH[idx];
#else
  uint8_t ch = 0;
#endif
  pwmWrite(SERVO_PINS[idx], ch, duty);

  Serial.print("[Servo] M");
  Serial.print(idx + 1);
  Serial.print(" angle=");
  Serial.print(angle);
  Serial.print(" pulse=");
  Serial.print(pulseUs);
  Serial.print("us duty=");
  Serial.println(duty);
}

// M2/M3 直接 PWM 输出（电平值 0-255）
void setServoLevel(uint8_t idx, uint8_t level) {
  // idx: 0=M2, 1=M3
  uint32_t maxDuty = (1UL << SERVO23_RES) - 1;
  uint32_t duty = (uint32_t)level * maxDuty / 255;
  duty = constrain(duty, 0, maxDuty);

  uint8_t pin = (idx == 0) ? SERVO2_PIN : SERVO3_PIN;
#if !LEDC_NEW_API
  uint8_t ch = SERVO23_CH[idx];
#else
  uint8_t ch = 0;
#endif
  pwmWrite(pin, ch, duty);
}

// ============================================================
// 电池电压检测
// ============================================================
float readBatteryVoltage() {
  const int samples = 20;
  long sum = 0;
  for (int i = 0; i < samples; i++) {
    sum += analogRead(BAT_PIN);
    delayMicroseconds(100);
  }
  float adcAvg = sum / (float)samples;
  float vAdc = adcAvg * ADC_REF / ADC_MAX;
  float divider = BAT_R2 / (BAT_R1 + BAT_R2);
  return vAdc / divider;
}

// 保留两位小数（用于遥测 JSON）
float round2(float value) {
  return round(value * 100.0) / 100.0;
}

// ============================================================
// 输出同步
// ============================================================
// 电机输出，带换向保护：检测到方向切换时先强制输出 0 一段时间
void applyMotorOutputs() {
  int signL = (motorL > 0) ? 1 : (motorL < 0) ? -1 : 0;
  int signR = (motorR > 0) ? 1 : (motorR < 0) ? -1 : 0;
  int appliedSignL = (appliedMotorL > 0) ? 1 : (appliedMotorL < 0) ? -1 : 0;
  int appliedSignR = (appliedMotorR > 0) ? 1 : (appliedMotorR < 0) ? -1 : 0;

  bool dirChanged =
    (signL != 0 && appliedSignL != 0 && signL != appliedSignL) ||
    (signR != 0 && appliedSignR != 0 && signR != appliedSignR);

  if (dirChanged && !directionChangeHolding) {
    directionChangeHolding = true;
    directionChangeHoldEnd = millis() + DIRECTION_CHANGE_HOLD_MS;
    Serial.println("[MotorProtect] 检测到电机换向，强制停转保护");
  }

  if (directionChangeHolding) {
    setMotor(0, 0);
    setMotor(1, 0);
    appliedMotorL = 0;
    appliedMotorR = 0;
    if ((int32_t)(millis() - directionChangeHoldEnd) >= 0) {
      directionChangeHolding = false;
    }
    return;
  }

  setMotor(0, motorL);
  setMotor(1, motorR);
  appliedMotorL = motorL;
  appliedMotorR = motorR;
}

// 输出同步
void applyOutputs() {
  applyMotorOutputs();
  setServo(0, servoM1);
  setServoLevel(0, servoM2);
  setServoLevel(1, servoM3);
}

void stopAllMotors() {
  motorL = 0;
  motorR = 0;
  setMotor(0, 0);
  setMotor(1, 0);
  appliedMotorL = 0;
  appliedMotorR = 0;
  directionChangeHolding = false;
}

// ============================================================
// MQTT 指令解析
// ============================================================
void parseCommand(const char* json) {
  JsonDocument doc;
  DeserializationError error = deserializeJson(doc, json);

  if (error) {
    Serial.print("[MQTT] JSON 解析失败: ");
    Serial.println(error.c_str());
    return;
  }

  // 所有字段均为可选；缺失字段保持上一次值
  if (doc.containsKey("L"))  motorL  = (int16_t)doc["L"];
  if (doc.containsKey("R"))  motorR  = (int16_t)doc["R"];
  if (doc.containsKey("M1")) servoM1 = (int16_t)doc["M1"];
  if (doc.containsKey("M2")) servoM2 = (uint8_t)doc["M2"];
  if (doc.containsKey("M3")) servoM3 = (uint8_t)doc["M3"];

  // RSSI 重连参数（可通过上位机实时调整）
  if (doc.containsKey("rssi_threshold")) {
    rssiReconnectThreshold = (int)doc["rssi_threshold"];
    rssiBelowThresholdSince = 0;
    Serial.printf("[WiFi] RSSI 重连阈值已更新为 %d dBm\n", rssiReconnectThreshold);
  }
  if (doc.containsKey("rssi_delay")) {
    rssiReconnectDelayMs = (unsigned long)doc["rssi_delay"];
    rssiBelowThresholdSince = 0;
    Serial.printf("[WiFi] RSSI 重连延迟已更新为 %lu ms\n", rssiReconnectDelayMs);
  }

  applyOutputs();
  lastCmdMs = millis();

  Serial.println("[MQTT] 已执行控制指令");
}

void mqttCallback(char* topic, byte* payload, unsigned int length) {
  if (strcmp(topic, TOPIC_CMD) != 0) return;

  char buf[MQTT_BUFFER_SIZE];
  if (length >= sizeof(buf)) length = sizeof(buf) - 1;
  memcpy(buf, payload, length);
  buf[length] = '\0';

  Serial.print("[MQTT] 收到指令: ");
  Serial.println(buf);

  parseCommand(buf);
}

// ============================================================
// 网络与 MQTT 连接
// ============================================================
void setupWiFi() {
  Serial.print("[WiFi] 连接 ");
  Serial.print(WIFI_SSID);
  WiFi.begin(WIFI_SSID, WIFI_PASS);

  int attempt = 0;
  while (WiFi.status() != WL_CONNECTED && attempt < 20) {
    delay(100);
    Serial.print(".");
    attempt++;
  }

  if (WiFi.status() == WL_CONNECTED) {
    Serial.println();
    Serial.print("[WiFi] 已连接，IP: ");
    Serial.println(WiFi.localIP());
  } else {
    Serial.println();
    Serial.println("[WiFi] 连接失败，稍后重试");
  }
}

bool ensureWiFi() {
  if (WiFi.status() == WL_CONNECTED) {
    int32_t rssi = WiFi.RSSI();
    if (rssi < rssiReconnectThreshold) {
      if (rssiBelowThresholdSince == 0) {
        rssiBelowThresholdSince = millis();
        Serial.printf("[WiFi] 控制板信号强度 %d dBm 低于阈值 %d dBm，开始计时 %lu ms\n",
                      rssi, rssiReconnectThreshold, rssiReconnectDelayMs);
      } else if (millis() - rssiBelowThresholdSince >= rssiReconnectDelayMs) {
        Serial.printf("[WiFi] 信号强度持续低于阈值 %lu ms，触发重连\n",
                      millis() - rssiBelowThresholdSince);
        rssiBelowThresholdSince = 0;
        WiFi.disconnect();
        delay(100);
        setupWiFi();
        wifiWasConnected = false;
        return (WiFi.status() == WL_CONNECTED);
      }
    } else {
      rssiBelowThresholdSince = 0;  // 信号恢复，重置计时
    }

    if (!wifiWasConnected) {
      Serial.println("[WiFi] 连接已恢复");
      mqttClient.disconnect();
    }
    wifiWasConnected = true;
    return true;
  }

  rssiBelowThresholdSince = 0;
  if (wifiWasConnected) {
    Serial.println("[WiFi] 连接断开，尝试重连...");
    wifiWasConnected = false;
  }
  WiFi.disconnect();
  setupWiFi();
  return (WiFi.status() == WL_CONNECTED);
}

void reconnectMQTT() {
  while (!mqttClient.connected()) {
    Serial.print("[MQTT] 尝试连接服务器...");
    bool ok;

    if (strlen(MQTT_USER) > 0) {
      ok = mqttClient.connect(MQTT_CLIENT_ID, MQTT_USER, MQTT_PASS);
    } else {
      ok = mqttClient.connect(MQTT_CLIENT_ID);
    }

    if (ok) {
      Serial.println("已连接");
      mqttClient.subscribe(TOPIC_CMD);
      Serial.print("[MQTT] 已订阅: ");
      Serial.println(TOPIC_CMD);
    } else {
      Serial.print("失败，状态码=");
      Serial.print(mqttClient.state());
      Serial.println("，0.3秒后重试");
      delay(300);
    }
  }
}

// ============================================================
// 遥测上报
// ============================================================
void publishTelemetry() {
  JsonDocument doc;

  doc["vbat"]   = round2(readBatteryVoltage());
  doc["L"]      = appliedMotorL;  // 上报实际输出到驱动芯片的值
  doc["R"]      = appliedMotorR;
  doc["M1"]     = servoM1;
  doc["M2"]     = servoM2;
  doc["M3"]     = servoM3;
  doc["ctrlrssi"]   = WiFi.RSSI();
  doc["uptime"] = millis();

  char buf[384];
  size_t n = serializeJson(doc, buf);

  bool ok = mqttClient.publish(TOPIC_TELEMETRY, buf, n);

  if (ok) {
    Serial.print("[Telemetry] ");
    Serial.println(buf);
  } else {
    Serial.println("[Telemetry] 发送失败，数据过大或网络断开");
  }
}

// ============================================================
// 初始化
// ============================================================
void setup() {
  Serial.begin(115200);
  delay(500);
  Serial.println("\n[Init] 玩具坦克 ESP32 控制板启动");

  // 配置 GPIO
  pinMode(LEFT_AIN1, OUTPUT);
  pinMode(LEFT_AIN2, OUTPUT);
  pinMode(RIGHT_BIN1, OUTPUT);
  pinMode(RIGHT_BIN2, OUTPUT);
  pinMode(STBY_PIN, OUTPUT);

  // 使能电机驱动板
  digitalWrite(STBY_PIN, HIGH);

  // 电机 PWM
  bool pwmOk = true;
  pwmOk &= pwmAttach(LEFT_PWM,  MOTOR_FREQ, MOTOR_RES, 0);
  pwmOk &= pwmAttach(RIGHT_PWM, MOTOR_FREQ, MOTOR_RES, 1);

  // 舵机 PWM
  pwmOk &= pwmAttach(SERVO1_PIN, SERVO_FREQ, SERVO_RES, 2);
  pwmOk &= pwmAttach(SERVO2_PIN, SERVO23_FREQ, SERVO23_RES, 5);
  pwmOk &= pwmAttach(SERVO3_PIN, SERVO23_FREQ, SERVO23_RES, 6);

  if (!pwmOk) {
    Serial.println("[Init] 部分 PWM 初始化失败，请检查引脚或 LEDC 通道");
  } else {
    Serial.println("[Init] PWM 初始化完成");
  }

  // 电池 ADC
  analogReadResolution(12);
  analogSetAttenuation(ADC_11db);

  // 初始状态：停车、舵机居中
  applyOutputs();

  // 舵机自检：M1 摆动，M2/M3 电平闪烁，便于确认硬件接线正常
  Serial.println("[Init] 舵机自检开始");
  setServo(0, 60);
  delay(150);
  setServo(0, 120);
  delay(150);
  setServo(0, 90);
  delay(100);
  setServoLevel(0, 128);
  setServoLevel(1, 128);
  delay(300);
  setServoLevel(0, 0);
  setServoLevel(1, 0);
  Serial.println("[Init] 舵机自检结束");

  // 网络
  setupWiFi();

  // MQTT
  mqttClient.setServer(MQTT_HOST, MQTT_PORT);
  mqttClient.setCallback(mqttCallback);
  mqttClient.setBufferSize(MQTT_BUFFER_SIZE);

  lastCmdMs   = millis();
  telemetryMs = millis();
}

// ============================================================
// 主循环
// ============================================================
void loop() {
  bool wifiOk = ensureWiFi();

  if (wifiOk) {
    if (!mqttClient.connected()) {
      reconnectMQTT();
    }
    mqttClient.loop();
  }

  // 看门狗：超时未收到指令则停车，伺服电机保持原位
  if (millis() - lastCmdMs > WATCHDOG_MS) {
    stopAllMotors();
    setServo(0, servoM1);
    setServoLevel(0, servoM2);
    setServoLevel(1, servoM3);
    // 只打印一次，避免刷屏
    static uint32_t lastWarn = 0;
    if (millis() - lastWarn > 1000) {
      Serial.println("[Watchdog] 指令超时，已自动停车，伺服保持原位");
      lastWarn = millis();
    }
  }

  // 定时遥测
  if (millis() - telemetryMs >= TELEMETRY_MS) {
    publishTelemetry();
    telemetryMs = millis();
  }

  delay(1);  // 喂 ESP32 看门狗
}

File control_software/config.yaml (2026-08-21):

# Copyright (c) 2026 eric6227
# Released under the MIT License. See LICENSE file in the project root for full text.
mqtt_host: 192.168.2.45
mqtt_port: 1883
mqtt_topic: tank/telemetry/control
mqtt_monitor_topic: tank/telemetry/monitor
mqtt_username: ''
stream_url: http://192.168.2.188:81/stream
cam_resolution: 1280x720 (HD)
cam_quality: 20
cam_fps: 60
audio_port: 5004
stream_output_port: 8080
volume: 71
audio_enabled: true
control_key_forward: 16777235
control_key_backward: 16777237
control_key_left: 16777234
control_key_right: 16777236
control_key_boost: 66
control_key_shift_up: 81
control_key_shift_down: 65
control_key_mode_toggle: 77
control_max_output_pct: 70
control_boost_output_pct: 95
control_boost_max_ms: 15000
control_accel_rate_pct: 8
control_brake_strength_pct: 50
control_steering_factor: 0.4
control_steering_factor_high: 0.4
control_steering_factor_low: 0.4
control_steering_factor_reverse: 0.4
control_steering_factor_inplace: 0.4
control_reverse_steering_invert: true
control_wifi_cam_rssi_reconnect_threshold_dbm: -80.0
control_wifi_cam_rssi_reconnect_delay_ms: 1000
control_wifi_ctrl_rssi_reconnect_threshold_dbm: -80.0
control_wifi_ctrl_rssi_reconnect_delay_ms: 1000
control_upshift_threshold: 0.6
control_downshift_threshold: 0.25
control_shift_blip_pct: 5
control_low_ratio: -0.8
control_high_ratio: 1.25
control_m1_low: 0
control_m1_high: 180
control_shift_time_s: 0.02
control_direction_change_hold_ms: 50
control_m1_speed_deg_per_tick: 3
servo_count: 2
servo_1_name: 逗猫棒
servo_1_seg_count: 1
servo_1_idle_level: 0
servo_1_seg1_key: 0
servo_1_seg1_level: 128
servo_1_seg1_time_s: 0.5
servo_1_seg1_mode: hold
servo_1_seg2_key: 0
servo_1_seg2_level: 255
servo_1_seg2_time_s: 0.5
servo_1_seg2_mode: toggle
servo_2_name: 大灯
servo_2_seg_count: 2
servo_2_idle_level: 0
servo_2_seg1_key: 68
servo_2_seg1_level: 200
servo_2_seg1_time_s: 0.5
servo_2_seg1_mode: toggle
servo_2_seg2_key: 83
servo_2_seg2_level: 255
servo_2_seg2_time_s: 0.01
servo_2_seg2_mode: hold
servo_3_name: 伺服3
servo_3_seg_count: 2
servo_3_idle_level: 0
servo_3_seg1_key: 0
servo_3_seg1_level: 0
servo_3_seg1_time_s: 0.5
servo_3_seg1_mode: toggle
servo_3_seg2_key: 0
servo_3_seg2_level: 0
servo_3_seg2_time_s: 0.5
servo_3_seg2_mode: toggle
video_flip_h: false
video_flip_v: false
video_rotation: 180
auto_quality_enabled: true
auto_quality_low_rssi: -70
auto_quality_recover_rssi: -60
auto_quality_low_resolution: 1280x720 (HD)
auto_quality_low_quality: 60
auto_quality_low_fps: 30

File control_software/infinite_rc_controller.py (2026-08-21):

# Copyright (c) 2026 eric6227
# Released under the MIT License. See LICENSE file in the project root for full text.
"""
无限遥控车控制器

架构：
    - 内置本地 HTTP 服务器，提供一个带 HUD 叠加的网页
    - 网页直接加载 ESP32-CAM 视频流，并用 JS 轮询 /telemetry 显示遥测
    - 上位机主窗口使用 QWebEngineView 显示该网页
    - OBS 浏览器源也能拉取同一个网页，画面完全一致

依赖：
    pip install PyQt6 PyQt6-WebEngine paho-mqtt opencv-python numpy pyyaml keyring sounddevice

用法：
    python infinite_rc_controller.py
"""

import json
import os
import queue
import socket
import sys
import threading
import time
from datetime import datetime
from http.server import BaseHTTPRequestHandler, ThreadingHTTPServer
from typing import Any, Dict, Optional, Union

import cv2
import keyring
import numpy as np
import paho.mqtt.client as mqtt
import requests
import sounddevice as sd
import yaml

from PyQt6.QtCore import Qt, QThread, QTimer, pyqtSignal, QUrl, QEvent
from PyQt6.QtGui import QColor, QFont, QKeySequence
from PyQt6.QtWebEngineWidgets import QWebEngineView
from PyQt6.QtWidgets import (
    QApplication,
    QCheckBox,
    QComboBox,
    QDoubleSpinBox,
    QFormLayout,
    QFrame,
    QHBoxLayout,
    QLabel,
    QLineEdit,
    QKeySequenceEdit,
    QMainWindow,
    QPushButton,
    QScrollArea,
    QSlider,
    QSpinBox,
    QTabWidget,
    QVBoxLayout,
    QWidget,
)

# 这是控制软件的默认预设配置文件：默认与控制软件入口同目录。
# 运行时优先从这里读取 yaml，并在缺失时落回 DEFAULT_CONFIG。
CONFIG_FILE = os.path.join(os.path.dirname(__file__), "config.yaml")
APP_NAME = "无限遥控车控制器"
KEYRING_SERVICE = "infinite_rc_controller"
KEYRING_USERNAME = "mqtt_password"

# 摄像头断流时用于保持 OBS 流不卡住的占位黑帧
_, _no_signal_buf = cv2.imencode(".jpg", np.zeros((480, 640, 3), dtype=np.uint8))
NO_SIGNAL_JPEG: bytes = _no_signal_buf.tobytes()

DEFAULT_CONTROL_TELEMETRY_TOPIC = "tank/telemetry/control"
DEFAULT_MONITOR_TELEMETRY_TOPIC = "tank/telemetry/monitor"
LEGACY_CONTROL_TELEMETRY_TOPIC = "tank/telemetry"

DEFAULT_CONFIG: Dict[str, Any] = {
    "mqtt_host": "192.168.2.45",
    "mqtt_port": 1883,
    "mqtt_topic": DEFAULT_CONTROL_TELEMETRY_TOPIC,
    "mqtt_monitor_topic": DEFAULT_MONITOR_TELEMETRY_TOPIC,
    "mqtt_username": "",
    "stream_url": "http://192.168.2.188:81/stream",
    "cam_resolution": "1280x720 (HD)",
    "cam_quality": 15,
    "cam_fps": 60,
    "audio_port": 5004,
    "stream_output_port": 8080,
    "volume": 71,
    "audio_enabled": True,
    # 控制
    "control_key_forward": 16777235,
    "control_key_backward": 16777237,
    "control_key_left": 16777234,
    "control_key_right": 16777236,
    "control_key_boost": 66,
    "control_key_shift_up": 81,
    "control_key_shift_down": 65,
    "control_key_mode_toggle": 77,
    "control_max_output_pct": 70,
    "control_boost_output_pct": 95,
    "control_boost_max_ms": 15000,
    "control_accel_rate_pct": 8,
    "control_brake_strength_pct": 50,
    "control_steering_factor": 0.4,
    "control_steering_factor_high": 0.4,
    "control_steering_factor_low": 0.4,
    "control_steering_factor_reverse": 0.4,
    "control_steering_factor_inplace": 0.4,
    "control_reverse_steering_invert": True,
    "control_wifi_cam_rssi_reconnect_threshold_dbm": -70.0,
    "control_wifi_cam_rssi_reconnect_delay_ms": 2000,
    "control_wifi_ctrl_rssi_reconnect_threshold_dbm": -75.0,
    "control_wifi_ctrl_rssi_reconnect_delay_ms": 2000,
    "control_upshift_threshold": 0.6,
    "control_downshift_threshold": 0.25,
    "control_shift_blip_pct": 5,
    "control_low_ratio": -0.8,
    "control_high_ratio": 1.846,
    "control_m1_low": 0,
    "control_m1_high": 180,
    "control_shift_time_s": 0.02,
    "control_direction_change_hold_ms": 50,
    "control_m1_speed_deg_per_tick": 3,
    # 伺服电机控制（默认2个，M1为换挡舵机保留）
    # 使用电平值(0-255)，直接输出到M2/M3引脚的PWM
    # 按下某段按键：当前为该段→回到不触发，否则→切换到该段
    "servo_count": 2,
    "servo_1_name": "逗猫棒",
    "servo_1_seg_count": 1,
    "servo_1_idle_level": 0,
    "servo_1_seg1_key": 0,
    "servo_1_seg1_level": 128,
    "servo_1_seg1_time_s": 0.5,
    "servo_1_seg1_mode": "hold",
    "servo_1_seg2_key": 0,
    "servo_1_seg2_level": 255,
    "servo_1_seg2_time_s": 0.5,
    "servo_1_seg2_mode": "toggle",
    "servo_2_name": "大灯",
    "servo_2_seg_count": 2,
    "servo_2_idle_level": 0,
    "servo_2_seg1_key": 68,
    "servo_2_seg1_level": 128,
    "servo_2_seg1_time_s": 0.5,
    "servo_2_seg1_mode": "toggle",
    "servo_2_seg2_key": 83,
    "servo_2_seg2_level": 255,
    "servo_2_seg2_time_s": 0.5,
    "servo_2_seg2_mode": "hold",
    "servo_3_name": "伺服3",
    "servo_3_seg_count": 2,
    "servo_3_idle_level": 0,
    "servo_3_seg1_key": 0,
    "servo_3_seg1_level": 0,
    "servo_3_seg1_time_s": 0.5,
    "servo_3_seg1_mode": "toggle",
    "servo_3_seg2_key": 0,
    "servo_3_seg2_level": 0,
    "servo_3_seg2_time_s": 0.5,
    "servo_3_seg2_mode": "toggle",
    "video_flip_h": False,
    "video_flip_v": False,
    "video_rotation": 0,
    "auto_quality_enabled": False,
    "auto_quality_low_rssi": -80,
    "auto_quality_recover_rssi": -70,
    "auto_quality_low_resolution": "320x240 (QVGA)",
    "auto_quality_low_quality": 30,
    "auto_quality_low_fps": 10,
}


def load_config() -> Dict[str, Any]:
    cfg = dict(DEFAULT_CONFIG)
    if os.path.exists(CONFIG_FILE):
        try:
            with open(CONFIG_FILE, "r", encoding="utf-8") as f:
                loaded = yaml.safe_load(f)
                if isinstance(loaded, dict):
                    cfg.update(loaded)
        except Exception:
            pass
    try:
        password = keyring.get_password(KEYRING_SERVICE, KEYRING_USERNAME)
    except Exception:
        password = None
    cfg["mqtt_password"] = password if password else ""
    return cfg


def save_config_silent(cfg: Dict[str, Any]) -> None:
    try:
        cfg_copy = dict(cfg)
        password = cfg_copy.pop("mqtt_password", "")
        if password:
            keyring.set_password(KEYRING_SERVICE, KEYRING_USERNAME, password)
        else:
            try:
                keyring.delete_password(KEYRING_SERVICE, KEYRING_USERNAME)
            except Exception:
                pass
        with open(CONFIG_FILE, "w", encoding="utf-8") as f:
            yaml.safe_dump(cfg_copy, f, allow_unicode=True, sort_keys=False)
    except Exception:
        pass


def create_mqtt_client() -> mqtt.Client:
    try:
        return mqtt.Client(callback_api_version=mqtt.CallbackAPIVersion.VERSION1)
    except AttributeError:
        return mqtt.Client()
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

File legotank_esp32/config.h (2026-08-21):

/*
 * Copyright (c) 2026 eric6227
 * Released under the MIT License. See LICENSE file in the project root for full text.
 *
 * 玩具坦克 ESP32 控制板配置文件
 * 根据你给出的引脚定义、PWM 参数和电池检测参数编写
 */

#ifndef TANK_CONFIG_H
#define TANK_CONFIG_H

// ========== 引脚定义 ==========
// 左电机 (TB6612FNG 或类似驱动)
#define LEFT_AIN1   4
#define LEFT_AIN2   5
#define LEFT_PWM    18

// 右电机
#define RIGHT_BIN1  19
#define RIGHT_BIN2  21
#define RIGHT_PWM   22

// STBY (驱动板使能)
#define STBY_PIN    23

// 舵机
#define SERVO1_PIN  25   // M1：换挡
#define SERVO2_PIN  26   // M2：大灯
#define SERVO3_PIN  27   // M3：晃动逗猫棒

// 电池检测 (GPIO34，ADC1_CH6)
#define BAT_PIN     34

// ========== PWM 参数 ==========
#define MOTOR_FREQ  20000   // 电机 PWM 频率 20kHz
#define MOTOR_RES   8       // 8 位分辨率 (0-255)

#define SERVO_FREQ  50      // 舵机 PWM 频率 50Hz
#define SERVO_RES   16      // 16 位分辨率 (0-65535)

#define SERVO23_FREQ  1200   // M2/M3 直接 PWM 频率 (4×300Hz，无频闪)
#define SERVO23_RES   8      // 8 位分辨率 (0-255)

// 舵机角度对应的脉宽（微秒），可按实际舵机微调
#define SERVO_MIN_US  1000   // 0°
#define SERVO_MAX_US  2000  // 180°

// ========== 电池检测参数 ==========
// 分压电阻：BAT+ ---[100k]--- ADC ---[30k]--- GND
// ADC 引脚电压 = Vbat * R2 / (R1 + R2)
#define BAT_R1      95100.0    // 实际值，电阻有误差
#define BAT_R2      26500.0      // 实际值，电阻有误差
#define ADC_REF     3.3
#define ADC_MAX     4095.0   // 12 位 ADC

// 3S LiPo 参考值（用于可选的电量百分比估算）
#define BAT_3S_MAX  12.6
#define BAT_3S_MIN  9.9

// ========== 网络 / MQTT 配置 ==========
// 请修改成你自己的 WiFi 和 MQTT 服务器信息
#define WIFI_SSID   "8-2-102"
#define WIFI_PASS   "go192837"

#define MQTT_HOST   "192.168.2.45"
#define MQTT_PORT   1883
#define MQTT_USER   ""        // 无认证时留空
#define MQTT_PASS   ""

// 主题定义
#define TOPIC_CMD        "tank/cmd"              // 上位机 -> ESP32 控制指令
#define TOPIC_TELEMETRY  "tank/telemetry/control" // ESP32 -> 上位机遥测数据

// MQTT 客户端 ID（建议每台设备唯一）
#define MQTT_CLIENT_ID   "tank-esp32-001"

// ========== 运行时参数 ==========
#define TELEMETRY_MS     50       // 遥测上报间隔（毫秒）
#define WATCHDOG_MS      500      // 指令超时保护（毫秒），超时自动停车
#define DIRECTION_CHANGE_HOLD_MS 50  // 电机换向时强制停转保持时间（毫秒）
#define MQTT_BUFFER_SIZE 1024     // MQTT 收发缓冲区

#endif // TANK_CONFIG_H
